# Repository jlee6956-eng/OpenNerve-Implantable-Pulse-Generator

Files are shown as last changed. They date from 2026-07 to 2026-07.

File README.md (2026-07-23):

# OpenNerve-Implantable-Pulse-Generator
Source files for the OpenNerve implantable pulse generator (IPG), charger, and user interface software

## Overview


The OpenNerve IPG is designed to enable researchers to develop novel therapies in the neuromodulation and bioelectronic medicine spaces. It is currently being used by a number of groups for acute and chronic preclinical studies, with plan to transition to clinical studies when ready.The IPG is capable of providing current-based bipolar electrical stimulation, measuring biosignals using multiple analog front ends (AFEs), and connecting with third-party sensors via an in-body I2C network. It communicates with a user controller over Bluetooth Low Energy (BLE) and can be easily configured to be rechargeable over inductive link. All source files are released under the CC-BY 4.0 open source copyright license, which requires attribution but allows their use for closed-source and commercial applications.

## Electronics
Two versions of the printed circuit board inside OpenNerve have been designed and manufactured. The [Gen1 PCBA](https://github.com/CARSSCenter/OpenNerve-Implantable-Pulse-Generator/Gen1%20PCBA) has eight pseudo-independent monopolar stimulation channels (configurable as four bipolar channels), two differential biosignal amplifiers for recording ECG, EMG, or eCAPS, and an I2C port for connection to an accelerometer or other in-body digital sensors. The [Gen2 PCBA](https://github.com/CARSSCenter/OpenNerve-Implantable-Pulse-Generator/tree/main/Gen2%20PCBA) has two fully independent bipolar stimulation channels capable of square wave stimulation up to 1200 Hz or low frequency sine wave stimulation, four configurable analog front ends, and an I2C port. See below for electrical specifications for the Gen2 IPG (square wave stimulation and analog front-ends).



## Firmware
OpenNerve contains two microcontrollers: an nRF52810 which controlls BLE communication (referred to as "BLE"), and an STM32 which controls most other functions (referred to as "MCU"). BLE firmware is the same for both Gen1 and Gen2 PCBAs and can be found [here](https://github.com/CARSSCenter/OpenNerve-Implantable-Pulse-Generator/tree/main/FW-BLE). Instructions for programming a new board can be found in the [BLE Flashing Guide](https://github.com/CARSSCenter/OpenNerve-Implantable-Pulse-Generator/blob/main/Docs/BLE-Flashing-Guide.md) under Docs. MCU firmware is different for Gen1 and Gen2 IPGs; the source code and hex files for each board's MCU firmware can be found in their respective folders, and instructions for compiling and flashing can be found at [MCU Flashing Guide](https://github.com/CARSSCenter/OpenNerve-Implantable-Pulse-Generator/blob/main/Docs/MCU-Flashing-Guide.md).

## Software
A Windows application has been written in VSCode to control OpenNerve's functions and download/save measurements. The source code for this app can be found in the [OpenNerve Windows App repo](https://github.com/CARSSCenter/OpenNerve-Windows-App). To communicate with OpenNerve using this app requires an encryption private key. To get the key used for the open-source builds of MCU2 firmware please reach out to carss@usc.edu. There are also instructions included [here](https://github.com/CARSSCenter/OpenNerve-Windows-App/blob/main/encryption-instructions.md) on how to create your own encryption keys and firmware build.

An Android app is also under development for communication and control with OpenNerve. Prototype code for this app can be found [here](https://github.com/CARSSCenter/OpenNerve-Android-App).

## Wireless charger
The OpenNerve IPG can be charged inductively using the [OpenNerve Charger](https://github.com/CARSSCenter/OpenNerve-Charger).

## Contributors
The OpenNerve IPG has been designed and manufactured in partnership with a number of contributors from the academic and private sectors, all of whom are committed to open source neurotech and lowering the barrier to developing new therapies. See below for a list of contributing organizations (last updated 22/01/2026).
* [Biomedical Microsystems Lab, University of Southern California](https://biomems.usc.edu/) - lead the larger CARSS center, set up and maintains open source resources, performs integration testing, software development, and preclinical studies
* [Med-Ally LLC](https://med-ally.com/) - designed the hermetic enclosure for OpenNerve, and provides final assembly services for chronic studies
* [Medipace Inc](https://www.medipaceinc.com/) - Manages electronics and firmware development, performs software development
* [Focus Uy](https://focus.uy/) - Designed the printed circuit board for OpenNerve IPG and charger
* [CoForce Ltd.](https://www.coforcemed.com/) - Peformed firmware development for OpenNerve
* [Veronica Rosado.](https://www.linkedin.com/in/veronica-rosado-silva/) - Developed Sine Wave Generator tool for OpenNerve
* [Julian Lee](https://www.linkedin.com/in/julian-lee-t/) - Worked on sine wave generator

Funding for OpenNerve has been provided by the US National Institutes of Health's SPARC program # [1U41NS129514](https://reporter.nih.gov/project-details/10557000) as well as by the US National Science Foundation's POSE Phase 1 program # [2449357](https://www.nsf.gov/awardsearch/show-award?AWD_ID=2449357). 

# Disclaimer

The contents of this repository are subject to revision. No representation or warranty, express or implied, is provided in relation to the accuracy, correctness, completeness, or reliability of the information, opinions, or conclusions expressed in this repository.

The contents of this repository (the “Materials”) are experimental in nature and should be used with prudence and appropriate caution. Any use is voluntary and at your own risk.

The Materials are made available “as is” by USC (the University of Southern California and its trustees, directors, officers, employees, faculty, students, agents, affiliated organizations and their insurance carriers, if any), its collaborators Med-Ally LLC and Medipace Inc., and any other contributors to this repository (collectively, “Providers”). Providers expressly disclaim all warranties, express or implied, arising in connection with the Materials, or arising out of a course of performance, dealing, or trade usage, including, without limitation, any warranties of title, noninfringement, merchantability, or fitness for a particular purpose.

Any user of the Materials agrees to forever indemnify, defend, and hold harmless Providers from and against, and to waive any and all claims against Providers for any and all claims, suits, demands, liability, loss or damage whatsoever, including attorneys' fees, whether direct or consequential, on account of any loss, injury, death or damage to any person or (including without limitation all agents and employees of Providers and all property owned by, leased to or used by either Providers) or on account of any loss or damages to business or reputations or privacy of any persons, arising in whole or in part in any way from use of the Materials or in any way connected therewith or in any way related thereto.

The Materials, any related materials, and all intellectual property therein, are owned by Providers.

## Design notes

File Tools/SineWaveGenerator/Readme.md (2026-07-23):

We created a sine wave generator with tunable amplitude and frequency parameters suitable for testing neuromodulation hardware. The frequency ranges from 0.1 Hz to 5 kHz and the amplitude ranges from 1 mV to 100mV. We first wanted to use a quadrature oscillator circuit, but that required tuning three resistors and capacitors at the same time which was not plausible given the parts we had access to. Then, we pivoted to a different oscillator circuit that only required a a dual gang pot and a double pole rotary switch. Parts to adjust pairs of resistors and pairs of capacitors at the same time were much easier to come by. We implemented JFET Automatic Gain Control (AGC) to account for the loop gain required before the desired amplitude was achieved (setting the loop gain above 1 while amplitude was not reached yet and setting loop gain to be 1 when amplitude was reached) To do so, we needed to find out what resistance the JFET would be at given different GS voltages. We also had to ensure that our rectifier circuit would work and would output a DC voltage proportional to the amplitude of the sine wave Our testing for that is listed in our LTspice simulations (Draft 4 is the new double integrator oscillator, Draft 1 is the old quadrature oscillator, Draft 2 is another quadrature oscillator that didn't work, Draft 3 was to test how to induce noise into the circuit, and Draft 12 was to test the resistance of the JFET given different GS voltages. In the PCB folder, we have our schematic and our layout. We also have Arduino code for the digital version of the sine wave generator that is still being developed. Below are the simulations that we recorded in LTspice:

Screenshot 2026-07-23 at 4 37 10 PM
failed quadrature oscillator simulation

List of Critical Components:

- OPA2188AID Op Amp (https://www.ti.com/lit/ds/symlink/opa2188.pdf?ts=1781621876407&ref_url=https%253A%252F%252Fwww.mouser.com%252F)
  - Zero drift, DC signals don't get integrated
- TLV172IDCK Op Amp (for buffers) (http://www.ti.com/lit/ds/symlink/tlv172.pdf)
  - Unity gain stable
- Rotary Encoder (for capacitor switches) (http://cdn-reichelt.de/documents/datenblatt/C200/DS-Serie%23LOR.pdf)
  - Negligable tracking error 
- USB_C Converter (https://www.usb.org/sites/default/files/documents/usb_type-c.zip)
  - Standard Component 
- SPI DAC (https://www.digikey.com/en/products/detail/analog-devices-inc/AD5683RARMZ/4759188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)
  - Satisfactory resolution 
- TT Electronics Dual Gang Pot (https://www.ttelectronics.com/TTElectronics/media/ProductFiles/Datasheet/PSxx.pdf)
  - Negligable tracking error
 
Future Tests: Upon receiving the manufactured board and the parts, we plan to first solder the components. The immediate next step is to ensure that our power converter is working when plugging in a USB-C cord. It should output 5V as Vcc. If not, we should connect the inductor to the oscilliscope to ensure our inductor is doing the switching movement.  Next, we should prove Vref to ensure that we are getting 2.5V. These two values are the most important to our schematic. Next, we can probe along different parts of our double integrator circuit to ensure that a sine waveform is actually being outputed. Next, we should probe our V_Sin_DC to ensure that we are getting a DC voltage proportional to the amplitude of the sine wave. Luckily, we have many test points that will making the debugging process a lot faster.

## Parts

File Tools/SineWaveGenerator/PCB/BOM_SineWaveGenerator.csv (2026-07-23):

Reference | Qty | Value | DNP | Exclude from BOM | Exclude from Board | Footprint | Description
0.1uF1,10uF1 | 2 | C |  |  |  | Capacitor_SMD:C_0805_2012Metric_Pad1.18x1.45mm_HandSolder | Unpolarized capacitor
C1,C6 | 2 | 22uF |  |  |  | Capacitor_SMD:C_0805_2012Metric_Pad1.18x1.45mm_HandSolder | Unpolarized capacitor
C2,C7 | 2 | 2.2uF |  |  |  | Capacitor_SMD:C_0805_2012Metric_Pad1.18x1.45mm_HandSolder | Unpolarized capacitor
C3,C8 | 2 | 220nF |  |  |  | Capacitor_SMD:C_0805_2012Metric_Pad1.18x1.45mm_HandSolder | Unpolarized capacitor
C4,C9 | 2 | 22nF |  |  |  | Capacitor_SMD:C_0805_2012Metric_Pad1.18x1.45mm_HandSolder | Unpolarized capacitor
C5,C10 | 2 | 3.3nF |  |  |  | Capacitor_SMD:C_0805_2012Metric_Pad1.18x1.45mm_HandSolder | Unpolarized capacitor
C11,C13,C17,C19,C25 | 5 | 100nF |  |  |  | Capacitor_SMD:C_0805_2012Metric_Pad1.18x1.45mm_HandSolder | Unpolarized capacitor
C12,C22,C26,C31,C32 | 5 | 0.1u |  |  |  | Capacitor_SMD:C_0805_2012Metric_Pad1.18x1.45mm_HandSolder | Unpolarized capacitor
C14,C16,C20,C24,C27 | 5 | 300pF |  |  |  | Capacitor_SMD:C_0805_2012Metric_Pad1.18x1.45mm_HandSolder | Unpolarized capacitor
C15 | 1 | 10nF |  |  |  | Capacitor_SMD:C_0805_2012Metric_Pad1.18x1.45mm_HandSolder | Unpolarized capacitor
C18,C28,C30 | 3 | 10uF |  |  |  | Capacitor_SMD:C_0805_2012Metric_Pad1.18x1.45mm_HandSolder | Unpolarized capacitor
C21,C29,C33,C34,C35,C36 | 6 | 0.1uF |  |  |  | Capacitor_SMD:C_0805_2012Metric_Pad1.18x1.45mm_HandSolder | Unpolarized capacitor
C23 | 1 | 1u |  |  |  | Capacitor_SMD:C_0603_1608Metric_Pad1.08x0.95mm_HandSolder | Unpolarized capacitor
D1 | 1 | D_TVS |  |  |  | Diode_SMD:D_SOD-323_HandSoldering | Bidirectional transient-voltage-suppression diode
D2,D3,D5,D6 | 4 | BAT54 |  |  |  | Diode_SMD:D_0805_2012Metric_Pad1.15x1.40mm_HandSolder | Schottky diode
F1 | 1 | Fuse |  |  |  | Fuse:Fuse_0805_2012Metric | Fuse
J1 | 1 | USB_C_Receptacle_USB2.0_14P |  |  |  | Connector_USB:USB_C_Receptacle_HRO_TYPE-C-31-M-12 | USB 2.0-only 14P Type-C Receptacle connector
J4 | 1 | SCLK |  |  |  | Connector_PinHeader_2.54mm:PinHeader_1x01_P2.54mm_Vertical | Generic connector, single row, 01x01, script generated
J5 | 1 | SYNC |  |  |  | Connector_PinHeader_2.54mm:PinHeader_1x01_P2.54mm_Vertical | Generic connector, single row, 01x01, script generated
J6 | 1 | SDI |  |  |  | Connector_PinHeader_2.54mm:PinHeader_1x01_P2.54mm_Vertical | Generic connector, single row, 01x01, script generated
J7 | 1 | V_dac_ref |  |  |  | Connector_PinHeader_2.54mm:PinHeader_1x01_P2.54mm_Vertical | Generic connector, single row, 01x01, script generated
J8 | 1 | VOUT |  |  |  | Connector_PinHeader_2.54mm:PinHeader_1x01_P2.54mm_Vertical | Generic connector, single row, 01x01, script generated
J9 | 1 | +5V |  |  |  | Connector_PinHeader_2.54mm:PinHeader_1x01_P2.54mm_Vertical | Generic connector, single row, 01x01, script generated
J10,J12 | 2 | GND |  |  |  | Connector_PinHeader_2.54mm:PinHeader_1x01_P2.54mm_Vertical | Generic connector, single row, 01x01, script generated
J11 | 1 | Out_Sin |  |  |  | Connector_PinHeader_2.54mm:PinHeader_1x01_P2.54mm_Vertical | Generic connector, single row, 01x01, script generated
L1 | 1 | 2.2uH |  |  |  | Inductor_SMD:L_Coilcraft_LPS3010 | Inductor
Q1 | 1 | Q_NJFET_DGS |  |  |  | JFET:TRANS_J201 | N-JFET transistor, drain/gate/source
R1,R2,R4,R12,R14,R18,R19,R20,R21,R26,R28 | 11 | 10k |  |  |  | Resistor_SMD:R_0805_2012Metric_Pad1.20x1.40mm_HandSolder | Resistor
R3 | 1 | 40k |  |  |  | Resistor_SMD:R_0805_2012Metric_Pad1.20x1.40mm_HandSolder | Resistor
R5,R11 | 2 | 5.1k |  |  |  | Resistor_SMD:R_0805_2012Metric_Pad1.20x1.40mm_HandSolder | Resistor
R6,R7 | 2 | 100 |  |  |  | Resistor_SMD:R_0805_2012Metric_Pad1.20x1.40mm_HandSolder | Resistor
R8,R9,R10,R16 | 4 | 100k |  |  |  | Resistor_SMD:R_0805_2012Metric_Pad1.20x1.40mm_HandSolder | Resistor
R13 | 1 | 540k |  |  |  | Resistor_SMD:R_0805_2012Metric_Pad1.20x1.40mm_HandSolder | Resistor
R15 | 1 | 127k |  |  |  | Resistor_SMD:R_0805_2012Metric_Pad1.20x1.40mm_HandSolder | Resistor
R17 | 1 | 25.5k |  |  |  | Resistor_SMD:R_0805_2012Metric_Pad1.20x1.40mm_HandSolder | Resistor
R22 | 1 | 25k |  |  |  | Resistor_SMD:R_0805_2012Metric_Pad1.20x1.40mm_HandSolder | Resistor
R23,R24 | 2 | 500 |  |  |  | Resistor_SMD:R_0805_2012Metric_Pad1.20x1.40mm_HandSolder | Resistor
R25 | 1 | 243k |  |  |  | Resistor_SMD:R_0805_2012Metric_Pad1.20x1.40mm_HandSolder | Resistor
RV1 | 1 | R_Potentiometer_Dual_Separate |  |  |  | Potentiometer_THT:DUALGANG_fixed | Dual potentiometer, separate units
RV2 | 1 | R_Potentiometer |  |  |  | Potentiometer_THT:BOURNS_POT | Potentiometer
SW1 | 1 | SW_Rotary_2x6 |  |  |  | Rotary_Encoder:SW_CK1050 | 2 rotary switch with 6 positions
TP1,TP2,TP3,TP4 | 4 | TestPoint |  |  |  | TestPoint:TestPoint_Pad_D1.0mm | test point
U2 | 1 | TPS63002DRCT |  |  |  | JFET:VREG_V62_16624-01YE | 96% Buck-Boost Converter with 1.7A Current Switches, 5V fixed Output voltage in 3x3 QFN
U4,U5,U13,U15,U16 | 5 | TLV172IDCK |  |  |  | Package_TO_SOT_SMD:SOT-353_SC-70-5 | Low-power Operational Amplifier, SOT-353
U6 | 1 | OPA2188AID |  |  |  | OPA2188AID:SOIC127P599X175-8N | 0.03µV/°C, 6µV Vos, Low Noise, Rail-to-Rail Output, 36V Zero-Drift Operational Amplifier
U7 | 1 |  |  |  |  | Package_SO:MSOP-10_3x3mm_P0.5mm
U10,U14 | 2 | TLV9061xDBV |  |  |  | Package_TO_SOT_SMD:SOT-23-5 | 10-MHz, RRIO, CMOS Operational Amplifiers for Cost-Sensitive Systems, SOT-23-5
U12 | 1 | OPA310xDBV |  |  |  | Package_TO_SOT_SMD:SOT-23-5 | High output current, Rail-to-Rail Input/Output, 3MHz GBW, Operational Amplifiers, integrated RFI/EMI filter, 1.5V to 5.5V supply, SOT-23-5

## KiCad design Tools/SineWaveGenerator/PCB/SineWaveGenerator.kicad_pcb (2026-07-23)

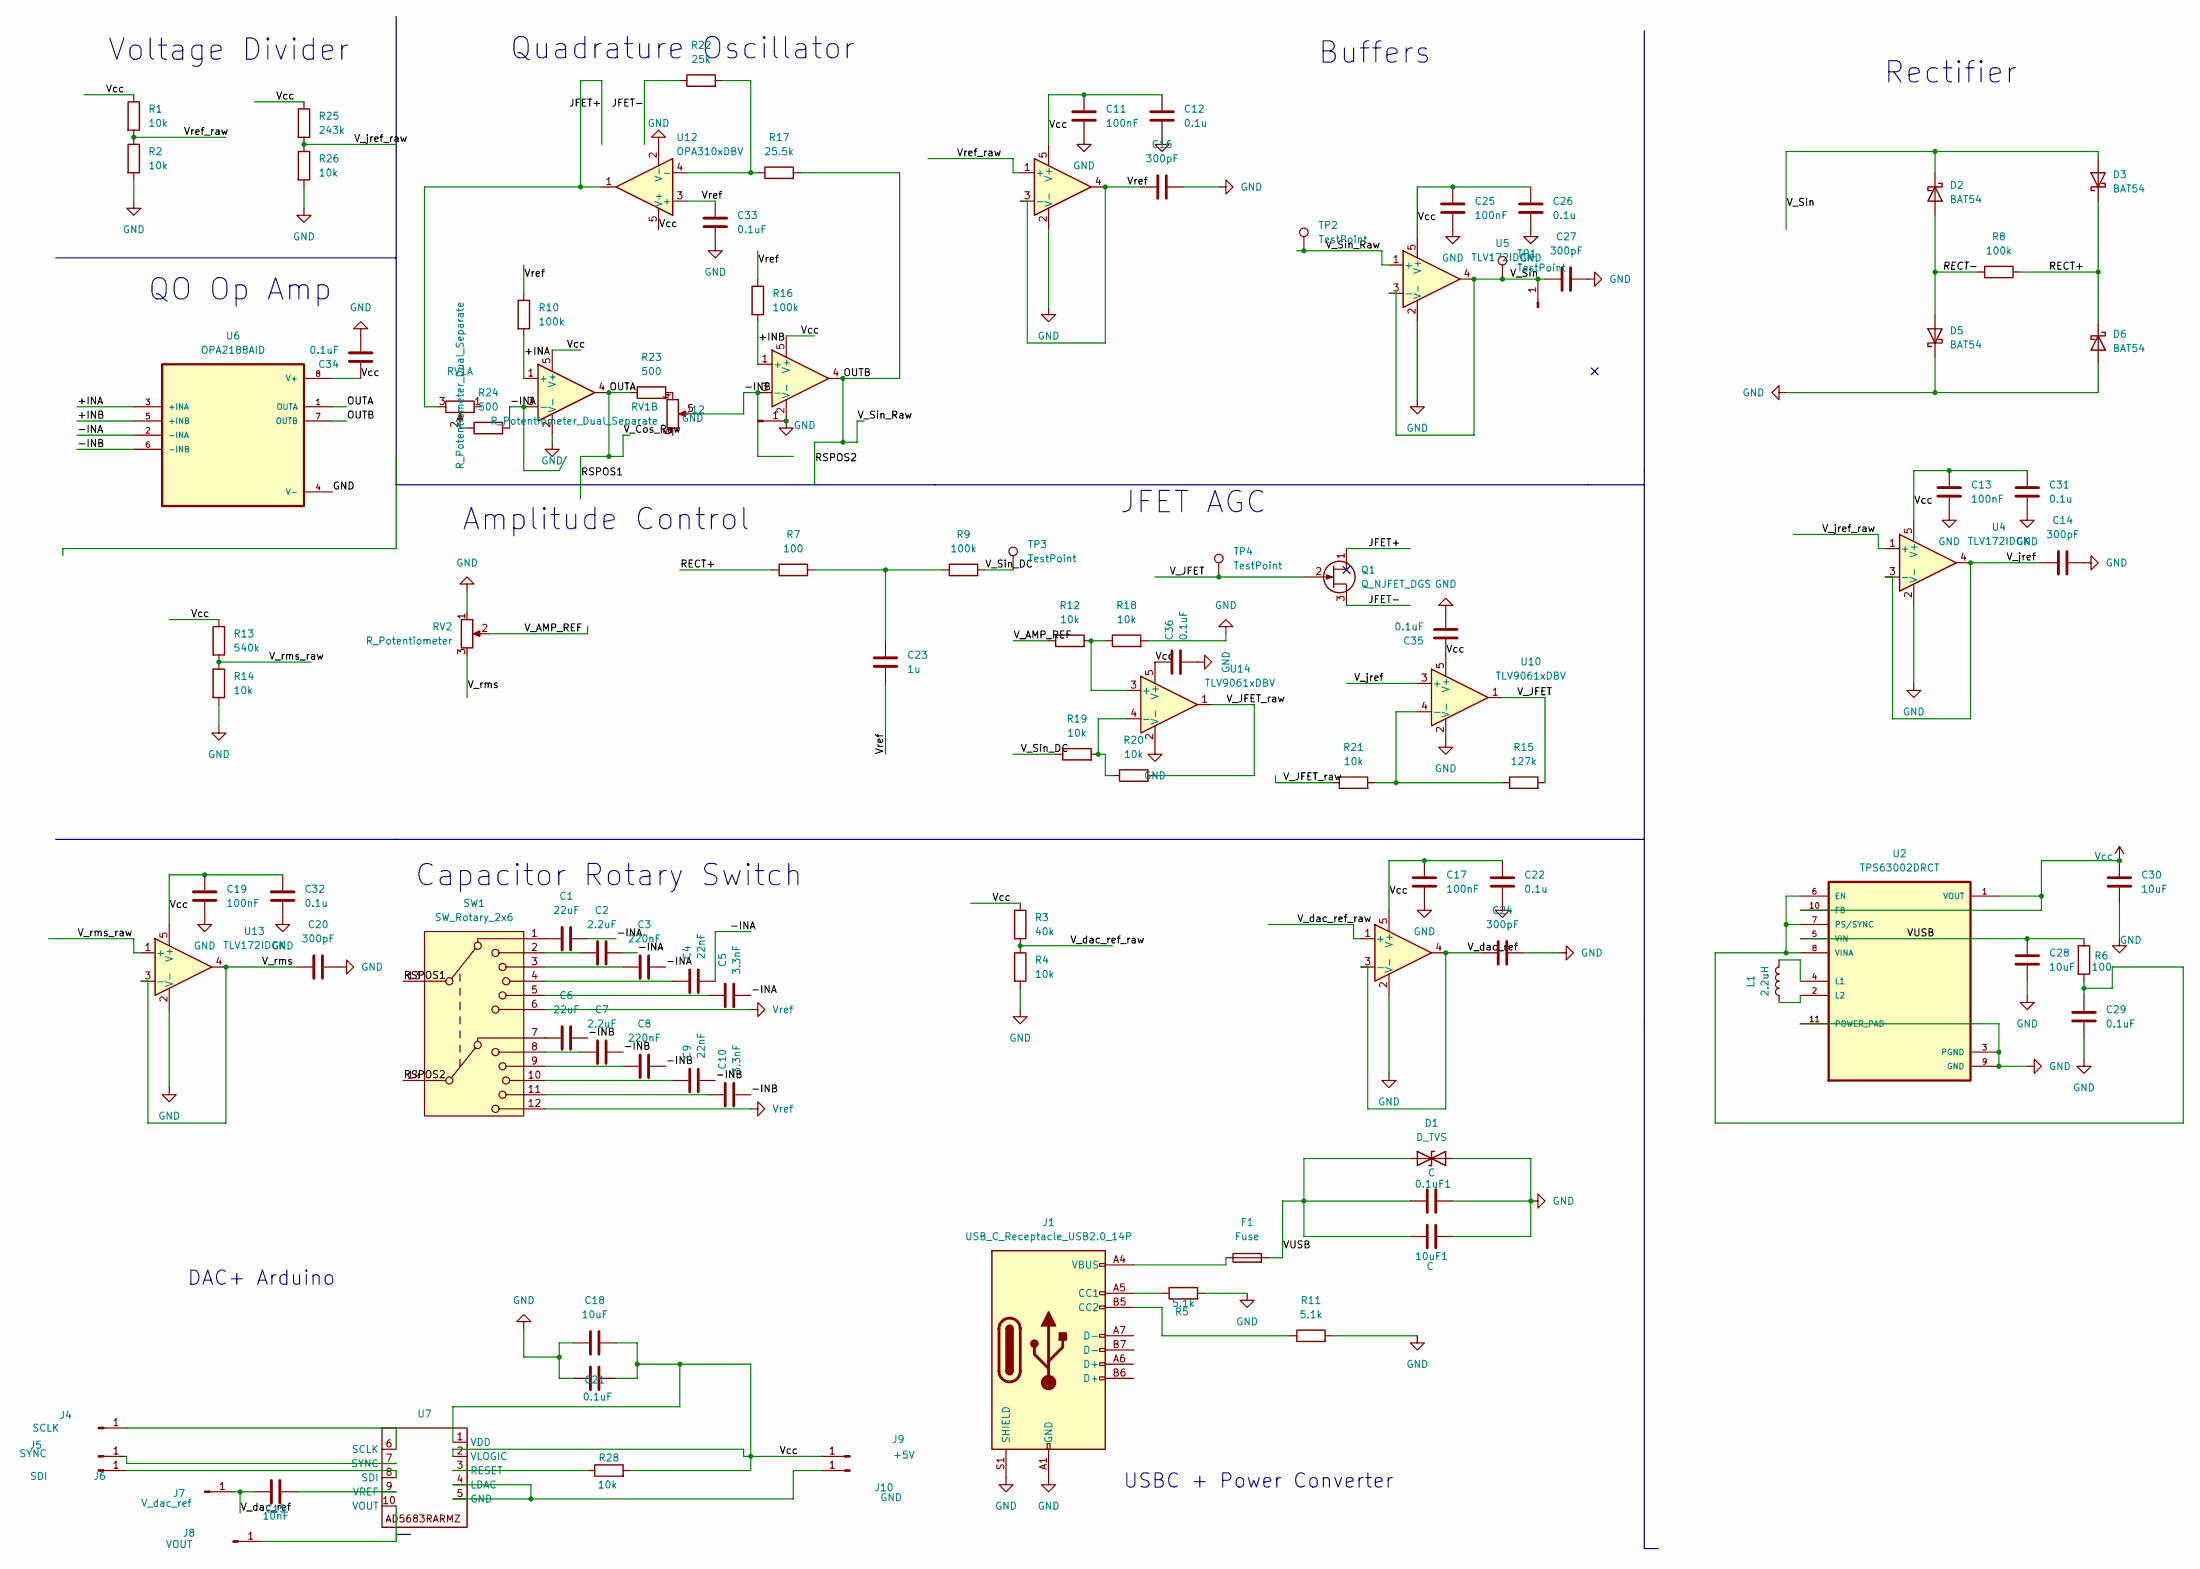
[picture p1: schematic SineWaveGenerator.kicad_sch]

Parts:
0.1uF1, 10uF1: C; C_0805_2012Metric_Pad1.18x1.45mm_HandSolder
C1, C6: 22uF; C_0805_2012Metric_Pad1.18x1.45mm_HandSolder
C2, C7: 2.2uF; C_0805_2012Metric_Pad1.18x1.45mm_HandSolder
C3, C8: 220nF; C_0805_2012Metric_Pad1.18x1.45mm_HandSolder
C4, C9: 22nF; C_0805_2012Metric_Pad1.18x1.45mm_HandSolder
C5, C10: 3.3nF; C_0805_2012Metric_Pad1.18x1.45mm_HandSolder
C11, C13, C17, C19, C25: 100nF; C_0805_2012Metric_Pad1.18x1.45mm_HandSolder
C12, C22, C26, C31, C32: 0.1u; C_0805_2012Metric_Pad1.18x1.45mm_HandSolder
C14, C16, C20, C24, C27: 300pF; C_0805_2012Metric_Pad1.18x1.45mm_HandSolder
C15: 10nF; C_0805_2012Metric_Pad1.18x1.45mm_HandSolder
C18, C28, C30: 10uF; C_0805_2012Metric_Pad1.18x1.45mm_HandSolder
C21, C29, C33, C34, C35, C36: 0.1uF; C_0805_2012Metric_Pad1.18x1.45mm_HandSolder
C23: 1u; C_0603_1608Metric_Pad1.08x0.95mm_HandSolder
D1: D_TVS; D_SOD-323_HandSoldering
D2, D3, D5, D6: BAT54; D_0805_2012Metric_Pad1.15x1.40mm_HandSolder
F1: Fuse; Fuse_0805_2012Metric
J1: USB_C_Receptacle_USB2.0_14P; USB_C_Receptacle_HRO_TYPE-C-31-M-12
J4: SCLK; PinHeader_1x01_P2.54mm_Vertical
J5: SYNC; PinHeader_1x01_P2.54mm_Vertical
J6: SDI; PinHeader_1x01_P2.54mm_Vertical
J7: V_dac_ref; PinHeader_1x01_P2.54mm_Vertical
J8: VOUT; PinHeader_1x01_P2.54mm_Vertical
J9: +5V; PinHeader_1x01_P2.54mm_Vertical
J10, J12: GND; PinHeader_1x01_P2.54mm_Vertical
J11: Out_Sin; PinHeader_1x01_P2.54mm_Vertical
L1: 2.2uH; L_Coilcraft_LPS3010
Q1: Q_NJFET_DGS; TRANS_J201
R1, R2, R4, R12, R14, R18, R19, R20, R21, R26, R28: 10k; R_0805_2012Metric_Pad1.20x1.40mm_HandSolder
R3: 40k; R_0805_2012Metric_Pad1.20x1.40mm_HandSolder
R5, R11: 5.1k; R_0805_2012Metric_Pad1.20x1.40mm_HandSolder
R6, R7: 100; R_0805_2012Metric_Pad1.20x1.40mm_HandSolder
R8, R9, R10, R16: 100k; R_0805_2012Metric_Pad1.20x1.40mm_HandSolder
R13: 540k; R_0805_2012Metric_Pad1.20x1.40mm_HandSolder
R15: 127k; R_0805_2012Metric_Pad1.20x1.40mm_HandSolder
R17: 25.5k; R_0805_2012Metric_Pad1.20x1.40mm_HandSolder
R22: 25k; R_0805_2012Metric_Pad1.20x1.40mm_HandSolder
R23, R24: 500; R_0805_2012Metric_Pad1.20x1.40mm_HandSolder
R25: 243k; R_0805_2012Metric_Pad1.20x1.40mm_HandSolder
RV1: R_Potentiometer_Dual_Separate; DUALGANG_fixed
RV2: R_Potentiometer; BOURNS_POT
SW1: SW_Rotary_2x6; SW_CK1050
TP1, TP2, TP3, TP4: TestPoint; TestPoint_Pad_D1.0mm
U2: TPS63002DRCT; VREG_V62_16624-01YE
U4, U5, U8, U11, U13, U15, U16: TLV172IDCK; SOT-353_SC-70-5
U6: OPA2188AID; SOIC127P599X175-8N
U7: MSOP-10_3x3mm_P0.5mm
U10, U14: TLV9061xDBV; SOT-23-5
U12: OPA310xDBV; SOT-23-5

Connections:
/+INA: R10.2, U6.3 (+INA), U8.1 (+)
/+INB: R16.2, U6.5 (+INB), U11.1 (+)
/-INA: C1.2, C2.2, C3.2, C4.2, C5.2, R24.2, U6.2 (-INA), U8.3 (-)
/-INB: C6.2, C7.2, C8.2, C9.2, C10.2, RV1.5, U6.6 (-INB), U11.3 (-)
/JFET+: Q1.1 (D), RV1.3, U12.1
/JFET-: Q1.3 (S), R22.1
/OUTA: R23.1, SW1.13, U6.1 (OUTA), U8.4
/OUTB: R17.2, SW1.14, TP2.1 (1_1), U5.1 (+), U6.7 (OUTB), U11.4
/RECT+: D3.1 (K), D6.1 (K), R7.1, R8.1
/RECT-: D2.2 (A), D5.2 (A), R8.2
/VUSB: 0.1uF1.1, 10uF1.1, C28.1, D1.1 (A1), F1.2, R6.1, U2.5 (VIN)
/V_AMP_REF: R12.1, RV2.2
/V_JFET: Q1.2 (G), R15.2, TP4.1 (1_1), U10.1
/V_JFET_raw: R20.2, R21.1, U14.1
/V_Sin: C27.1, D2.1 (K), D3.2 (A), J11.1 (Pin_1_1), TP1.1 (1_1), U5.3 (-), U5.4
/V_Sin_DC: R9.2, R19.1, TP3.1 (1_1)
/V_dac_ref: C15.1, C24.1, J7.1 (Pin_1_1), U16.3 (-), U16.4
/V_dac_ref_raw: R3.2, R4.1, U16.1 (+)
/V_jref: C14.1, U4.3 (-), U4.4, U10.3 (+)
/V_jref_raw: R25.2, R26.1, U4.1 (+)
/V_rms: C20.1, RV2.3, U13.3 (-), U13.4
/V_rms_raw: R13.2, R14.1, U13.1 (+)
/Vref_raw: R1.2, R2.1, U15.1 (+)
GND: 0.1uF1.2, 10uF1.2, C11.2, C12.2, C13.1, C14.2, C16.2, C17.2, C18.1, C19.1, C20.2, C21.1, C22.2, C24.2, C25.1, C26.2, C27.2, C28.2, C29.2, C30.2, C31.2, C32.2, C33.2, C34.2, C35.2, C36.2, D1.2 (A2), D5.1 (K), D6.2 (A), J1.A1 (GND), J1.A12 (GND), J1.B1 (GND), J1.B12 (GND), J1.S1 (SHIELD), J1.SH, J12.1 (Pin_1_1), R2.2, R4.2, R5.2, R11.2, R14.2, R18.2, R26.2, RV2.1, U2.3 (PGND), U2.9 (GND), U2.11 (POWER_PAD), U2.12, U2.13, U2.14, U2.15, U4.2 (V-), U5.2 (V-), U6.4 (V-), U8.2 (V-), U10.2 (V-), U11.2 (V-), U12.2 (V-), U13.2 (V-), U14.2 (V-), U15.2 (V-), U16.2 (V-)
unnamed: C1.1, SW1.1
unnamed: C2.1, SW1.2
unnamed: C3.1, SW1.3
unnamed: C4.1, SW1.4
unnamed: C5.1, SW1.5
unnamed: C6.1, SW1.7
unnamed: C7.1, SW1.8
unnamed: C8.1, SW1.9
unnamed: C9.1, SW1.10
unnamed: C10.1, SW1.11
unnamed: C23.1, R7.2, R9.1
unnamed: F1.1, J1.A4 (VBUS), J1.A9 (VBUS), J1.B4 (VBUS), J1.B9 (VBUS)
unnamed: J1.A5 (CC1), R5.1
unnamed: J1.B5 (CC2), R11.1
unnamed: J4.1 (Pin_1_1), U7.6 (SCLK)
unnamed: J5.1 (Pin_1_1), U7.7 (SYNC)
unnamed: J6.1 (Pin_1_1), U7.8 (SDI)
unnamed: J8.1 (Pin_1_1), U7.10 (VOUT)
unnamed: J10.1 (Pin_1_1), U7.4 (LDAC), U7.5 (GND)
unnamed: R23.2, RV1.4
unnamed: R24.1, RV1.2
unnamed: C29.1, R6.2, U2.6 (EN), U2.7 (PS/SYNC), U2.8 (VINA)
unnamed: L1.2, U2.4 (L1)
unnamed: L1.1, U2.2 (L2)
unnamed: R28.1, U7.3 (RESET)
unnamed: C15.2, U7.9 (VREF)
unnamed: R15.1, R21.2, U10.4 (-)
unnamed: R17.1, R22.2, U12.4 (-)
unnamed: R12.2, R18.1, U14.3 (+)
unnamed: R19.2, R20.1, U14.4 (-)
Vcc: C11.1, C12.1, C13.2, C17.1, C18.2, C19.2, C21.2, C22.1, C25.2, C26.1, C30.1, C31.1, C32.1, C34.1, C35.1, C36.1, J9.1 (Pin_1_1), R1.1, R3.1, R13.1, R25.1, R28.2, U2.1 (VOUT), U2.10 (FB), U4.5 (V+), U5.5 (V+), U6.8 (V+), U7.1 (VDD), U7.2 (VLOGIC), U8.5 (V+), U10.5 (V+), U11.5 (V+), U12.5 (V+), U13.5 (V+), U14.5 (V+), U15.5 (V+), U16.5 (V+)
Vref: C16.1, C23.2, C33.1, R10.1, R16.1, SW1.6, SW1.12, U12.3 (+), U15.3 (-), U15.4

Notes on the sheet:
Rectifier
Quadrature Oscillator
DAC+ Arduino
Buffers
QO Op Amp
Amplitude Control
Capacitor Rotary Switch
JFET AGC
USBC + Power Converter
Voltage Divider

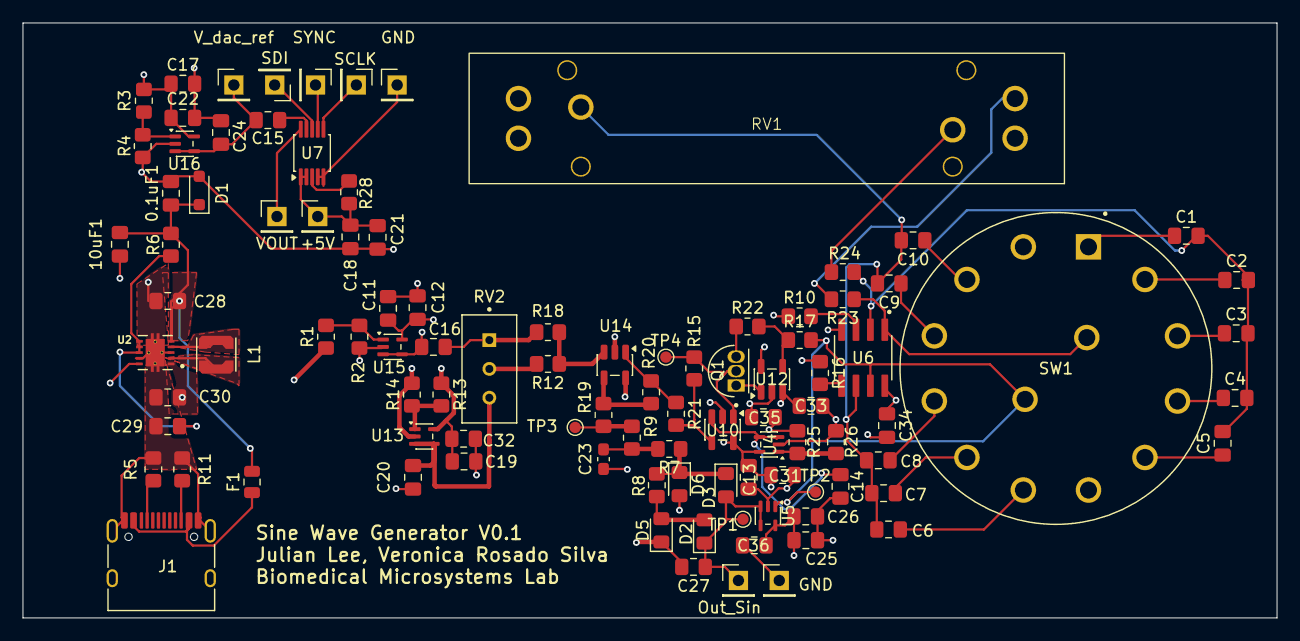
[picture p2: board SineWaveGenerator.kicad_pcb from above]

Board: 4 copper layers, 110.6 x 52.5 mm, 101 parts (0 on the bottom side), 56 nets.
